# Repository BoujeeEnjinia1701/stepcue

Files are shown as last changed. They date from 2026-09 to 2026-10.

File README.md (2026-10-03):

# StepCue

     

**Area:** BioMedical · **TRL:** 3 of 9 (proof of concept on paper) · **Prototype budget:** about $200 USD · **Difficulty:** 3 of 5

Pressure-sensing insole that detects the onset of a freeze and triggers a rhythmic haptic or audio cue.

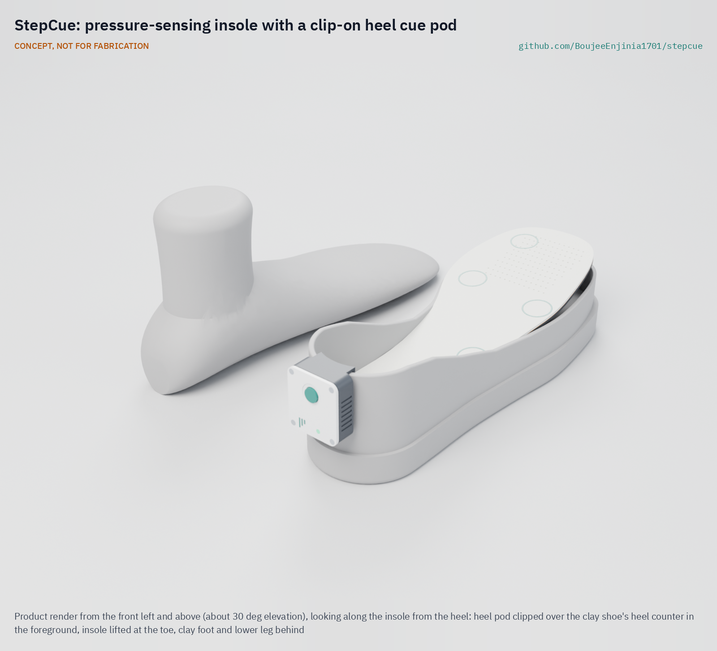
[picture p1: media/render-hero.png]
StepCue: pressure-sensing insole with a clip-on heel cue pod, product render


[Exploded render](media/render-exploded.png) · [Interactive 3D model](media/viewer.html) · [Concept blueprint (PDF)](media/concept-blueprint.pdf) · [General arrangement (PDF)](cad/drawings/STC-DWG-001.pdf) · [Sizing calculations](docs/04-calcs/01-sizing.md) · [Prototype build plan](docs/05-build-plan.md) · [Review note](docs/REVIEW.md)

## Concept rationale

Research systems that detect a freeze and cue only when it starts have mostly used accelerometers strapped to the shank, thigh or trunk, with the cue played through headphones. StepCue moves the sensing into the one place the wearer already puts on every day, the shoe: a thin insole reads how the foot is loading, a pod clipped to the heel counter holds the electronics and cell outside the shoe, and the default cue is a vibration under the arch, felt only by the wearer. Plantar pressure has predicted freezes in published work, and a foot-level design avoids straps and body-worn modules that people with reduced dexterity find hard to fit.

The design is open and garage-buildable so that the detector, the cue timing and the data format can be inspected and changed by clinics, researchers and patient groups rather than hidden in a closed product. It uses commercial force-sensing resistors, copper-tape traces on film, a common Bluetooth microcontroller module and 3D-printed parts, about $90 in parts for one instrumented insole and pod, against commercial cueing devices listed at £795 to £834. It is a research and educational prototype, not a medical device.

## Burning platform

The World Health Organization estimates that [more than 8.5 million people had Parkinson's disease in 2019 and that prevalence has doubled in the past 25 years](https://www.who.int/news-room/fact-sheets/detail/parkinson-disease). A meta-analysis of 29 studies put freezing of gait at [39.9 % of people with Parkinson's, rising to about 71 % after ten years with the disease](https://link.springer.com/article/10.1186/s41016-020-00197-y), and a Cochrane review notes that [most people with Parkinson's fall at least once during the course of the disease](https://www.cochrane.org/evidence/CD011574_interventions-preventing-falls-parkinsons-disease).

Cueing helps many people get moving again, but the devices that deliver it are costly and closed. The Path Finder shoe attachment is listed at [£834](https://techguide.parkinsons.org.uk/catalogue/path-finder) and the CUE1+ vibrotactile device at [£795 plus VAT](https://techguide.parkinsons.org.uk/catalogue/cue1plus), and the WHO notes that even the core medicine, levodopa, is [not accessible, available or affordable everywhere, particularly in low- and middle-income countries](https://www.who.int/news-room/fact-sheets/detail/parkinson-disease).

## Where it could be used

### By industry

| Industry | Use |
| --- | --- |
| Movement disorders research | Open reference platform for freeze detection and on-demand cueing studies, with a documented data format |
| Physiotherapy and rehabilitation | Adjustable cue tempo and a cue log to support home gait programs |
| Assistive technology and footwear | Reference design for sensing insoles that fit ordinary shoes |
| Biomedical engineering education | Teaching project in sensing, signal processing and embedded firmware with a clear safety envelope |
| Patient organizations and makerspaces | Low-cost builds for evaluation and co-design with people who freeze |

### By country or region

| Country or region | Why it matters there |
| --- | --- |
| China | About [5.1 million people with Parkinson's in 2021](https://www.sciencedirect.com/science/article/pii/S2666606524000725) (Xu et al., 2024), so low-cost cueing could reach many people |
| United Kingdom | Commercial cueing devices are listed at [£795 to £834](https://techguide.parkinsons.org.uk/catalogue/path-finder); an open design gives clinics and charities a cheaper research option |
| United States | About 930,000 people aged 45 and over with Parkinson's in 2020, projected to reach about 1.24 million by 2030 ([Marras et al., *npj Parkinson's Disease*, 2018](https://www.nature.com/articles/s41531-018-0058-0)); research groups could share one open detection platform and data format |
| India | The share of people aged 60 and over is projected to double to more than 20 % by 2050, and over 40 % of older people are in the poorest wealth quintile ([UNFPA India, 2023](https://india.unfpa.org/en/news/india-ageing-elderly-make-20-population-2050-unfpa-report)), so costly imported devices are out of reach for many |
| Sub-Saharan Africa | The WHO notes limited access to Parkinson's medicine in [low- and middle-income countries](https://www.who.int/news-room/fact-sheets/detail/parkinson-disease); a locally buildable cue aid needs no specialist supply chain |
| Brazil | About 535,000 people aged 50 and over were estimated to live with Parkinson's disease in 2024, projected to reach about 1.25 million by 2060 ([Schlickmann et al., *Lancet Regional Health: Americas*, 2025](https://www.sciencedirect.com/science/article/pii/S2667193X25000560)); locally built research devices can support rehabilitation studies |

## What sparked the idea

The starting point was the [wearable assistant built by ETH Zurich and the Tel Aviv Sourasky Medical Center in the EU Daphnet project](https://pubmed.ncbi.nlm.nih.gov/19906597/) (Bächlin et al., IEEE Transactions on Information Technology in Biomedicine, 2010). It used acceleration sensors on the legs and hip to detect freezes in ten people with Parkinson's and played a rhythmic sound to help them walk again, detecting 73.1 % of freezes at 81.6 % specificity, and most participants found the automatic cue helpful. That study proved that on-demand cueing works, and its recordings became a public benchmark, but its sensors were worn on the body and its cue was delivered through headphones. StepCue asks whether the same closed loop can live in the shoe: pressure under the foot plus a small heel pod, and a vibration the wearer feels rather than hears.

## Problem

Freezing of gait in Parkinson's causes falls, and cueing devices are expensive.

## Concept

A thin insole with five force-sensing resistors and a coin vibration motor connects by a flat flex tail to a small pod clipped over the heel of the shoe. The pod samples the pressure sensors and its own motion sensor 104 times a second, checks every 0.25 s for the pattern of a freeze, and pulses the motor at the wearer's own cadence until walking resumes; audio, where preferred, plays through a paired phone or earbuds. The TRL 3 calculations (STC-CAL-001) give $89.94 in parts for one instrumented insole and heel pod, a 4.5 mm insole stack and 12.5 days per charge (7.4 conservative). Detection speed, reliability and nuisance cues are at risk and cannot be shown without labeled data.

Full design precis: [docs/02-concept.md](docs/02-concept.md)

## Key components

- Force-sensing resistors (5)
- Laminated sensor film with a flat flex tail
- nRF52840 controller module with built-in 6-axis IMU in a clip-on heel pod
- Coin vibration motor under the arch
- 400 mAh protected LiPo cell (in the pod, outside the shoe)

The working bill of materials is in [bom/bom.csv](bom/bom.csv).

## Building the prototype

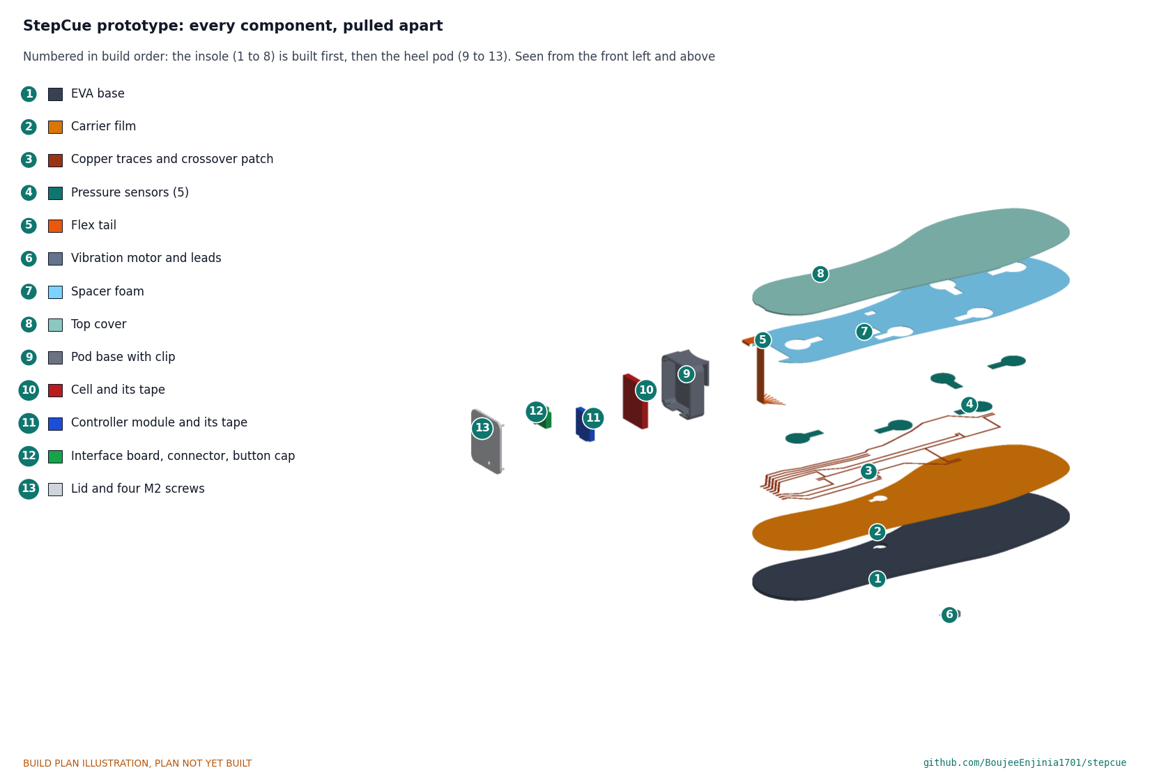
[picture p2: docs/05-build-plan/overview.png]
StepCue prototype: every component pulled apart and numbered in build order


The [prototype build plan](docs/05-build-plan.md) (STC-BLD-001) shows, in pictures, how to make each of the thirteen components and put them together in fourteen steps; nothing has been built yet. The insole is four layers cut with a knife, with a hand-laid copper tape circuit on a polyimide film joining five pressure sensors and a coin motor to a flat flex tail; the heel pod is two 3D prints holding a bought controller module, a protected cell and a hand-wired interface board. Writing the plan made the design buildable: the sensor laminate became a carrier film and a foam spacer, the motor moved into a through-hole, the tail got a connector inside the pod, the clip was curved to the heel counter and the lid gained four screws (STC-DDR-003, accepted by Amish on 2026-10-02). The insole outline is one smooth curve and the pod's corners are rounded to 5 mm with a parting-line groove. Every picture is drawn from the model, and the model checks that each part touches what it should and clears what it should not. It is a bench prototype for research and education, not a medical device.

## Safety

> This is a research and educational prototype. It is not a medical device, has not been cleared or approved by any regulator, and must not be used to diagnose, treat or monitor any person, or relied on to prevent falls. The heel pod holds a lithium cell: use a protected cell and never charge it while worn.

## Repository layout

| Folder | Contents |
| --- | --- |
| `docs/` | Problem, concept, requirements, calculations and design decisions |
| `cad/src/` | build123d Python source, the source of truth for all geometry |
| `cad/step/`, `cad/stl/` | Exported models for FreeCAD, other CAD tools and printing |
| `cad/drawings/` | 2D sketches and dimensioned drawings |
| `bom/` | Bill of materials |
| `electronics/` | KiCad schematics and PCB layouts |
| `firmware/` | Microcontroller code |
| `media/` | Renders, perspectives and photos |
| `build-log/` | Dated prototyping notes |

## Documentation

Controlled documents follow the portfolio [documentation standard](.kit/STANDARDS.md). Each carries a document ID (STC-PRC-001 for the precis), a version and a revision history. Branded PDFs are built with `python .kit/render.py` and attached to GitHub Releases when a document is tagged, for example `STC-PRC-001/v1.0`.

## Credits

Designed by Amish Chadha, with contributions from Dr. Geeti Chadha. See [CONTRIBUTORS.md](CONTRIBUTORS.md) for roles. To cite this design, use [CITATION.cff](CITATION.cff) (GitHub shows it as "Cite this repository").

AI assistance (Claude) was used to accelerate concept renders, prototype documentation and first-pass sizing calculations. Design direction and all decisions are Amish Chadha's, recorded in this repository's decision records (`docs/decisions/`).

## Licenses

- **Hardware** (CAD, drawings, BOM, electronics): [CERN-OHL-S v2](LICENSE)
- **Software** (firmware, scripts, notebooks): [MIT](LICENSE-SOFTWARE)

A project of the [Design Molecule](https://designmolecule.com) lab.

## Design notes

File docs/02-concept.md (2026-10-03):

---
doc_id: STC-PRC-001
title: StepCue design precis
project: StepCue
doc_type: Design precis
version: "0.7"
status: Draft
date: '2026-10-02'
author: Amish Chadha
license: CERN-OHL-S-2.0
revisions:
- version: "0.1"
  date: '2026-09-24'
  author: Amish Chadha
  change: Initial scaffold
- version: "0.2"
  date: '2026-09-25'
  author: Amish Chadha
  change: Populate to TRL 2 (architecture, first-order numbers, safety, media)
- version: "0.3"
  date: '2026-09-25'
  author: Amish Chadha
  change: TRL 3 (decisions D1 to D8 recorded, nRF52840 controller, piezo removed, numbers from STC-CAL-001, parametric model and STC-DWG-001)
- version: "0.4"
  date: '2026-09-25'
  author: Amish Chadha
  change: Recommendations accepted by Amish (DDR-002); 2.5 mm EVA base with motor relief, audio-route cue target, STC-DWG-001 Rev P2
- version: "0.5"
  date: '2026-10-01'
  author: Amish Chadha
  change: Design for construction (STC-DDR-003, draft); components, figures and key numbers updated from STC-CAL-001 v0.3; STC-DWG-001 Rev P3
- version: "0.6"
  date: '2026-10-02'
  author: Amish Chadha
  change: "Design for construction accepted; partner, charging, pod, traces and next model revision as decided on 2026-10-02 (STC-DEC-001)"
- version: "0.7"
  date: '2026-10-02'
  author: Amish Chadha
  change: Smooth spline insole outline and rounded pod with parting-line groove now in the model; pod mass from STC-CAL-001 v0.4; STC-DWG-001 Rev P4
---

# StepCue design precis

StepCue is a thin insole with five force-sensing resistors and a coin vibration motor, wired by a flat flex tail to a small pod that clips over the heel of the shoe. The pod reads the pressure sensors and its own motion sensor 104 times a second, decides every 0.25 s whether a freeze is starting, and if so pulses the motor at the wearer's own walking rhythm until steps resume. The calculation note STC-CAL-001 puts one unit at $89.94 in parts and 12.5 days per charge (7.4 days conservative). The insole stack is 4.50 mm against a 5.0 mm limit. Whether the detector is fast and reliable enough (R3 to R5) cannot be shown on paper and is the main risk; the calculations show those three requirements pull against one another.

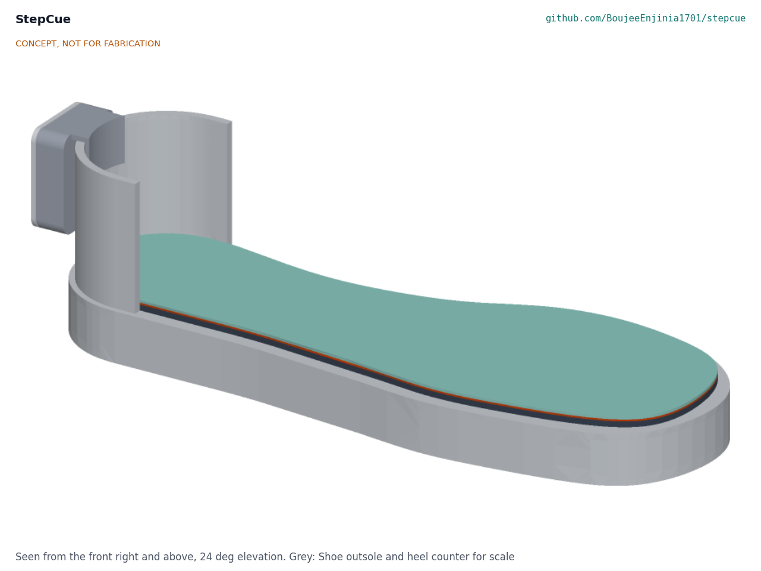
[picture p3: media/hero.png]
StepCue concept: instrumented insole in a shoe (grey), with the heel pod clipped over the heel counter


*Figure 1. Hero render from the TRL 3 parametric model. The grey shoe outsole and heel counter are shown for scale only.*

## How it works

1. **Sense.** Five force-sensing resistors (FSRs) laminated into the insole measure load under the heel, the lateral midfoot, the first and fifth metatarsal heads and the hallux. The 6-axis IMU on the controller module in the heel pod measures the motion of the shoe. All six signals are sampled at 104 Hz on the IMU's data-ready tick.
2. **Learn the wearer's rhythm.** A 30 s walk at the start of the day (or a stored value) sets the wearer's baseline cadence. Research systems such as GaitAssist used the same idea to tune cue tempo automatically ([Sweeney et al., Sensors, 2019](https://www.mdpi.com/1424-8220/19/6/1277)).
3. **Detect.** Every 0.25 s the firmware looks back over a 2 s window and computes a small set of features: whether heel strikes and toe-offs still alternate, how the center of pressure moves, the stride time compared with baseline, and the freeze index from the IMU (power in the 3 to 8 Hz freeze band divided by power in the 0.5 to 3 Hz locomotor band). The first detector is a set of thresholds; a small trained classifier replaces it once labeled data are available (decision D6). Plantar pressure alone has predicted freezes about 0.8 s before onset in the literature ([Pardoel et al., Frontiers in Neurology, 2022](https://www.frontiersin.org/articles/10.3389/fneur.2022.831063/pdf)).
4. **Cue.** When the detector fires, the coin motor under the arch pulses for 100 ms on each beat at the baseline cadence. Where the wearer prefers audio, the pod sends the beat timing over BLE to a paired phone, which plays it through its speaker or earbuds (decision D5). Cueing stops after three regular steps or 15 s, whichever comes first.
5. **Log.** Each cue is logged with a time stamp so the wearer or a clinician can later count cue events. The log leaves the pod only when the owner exports it.

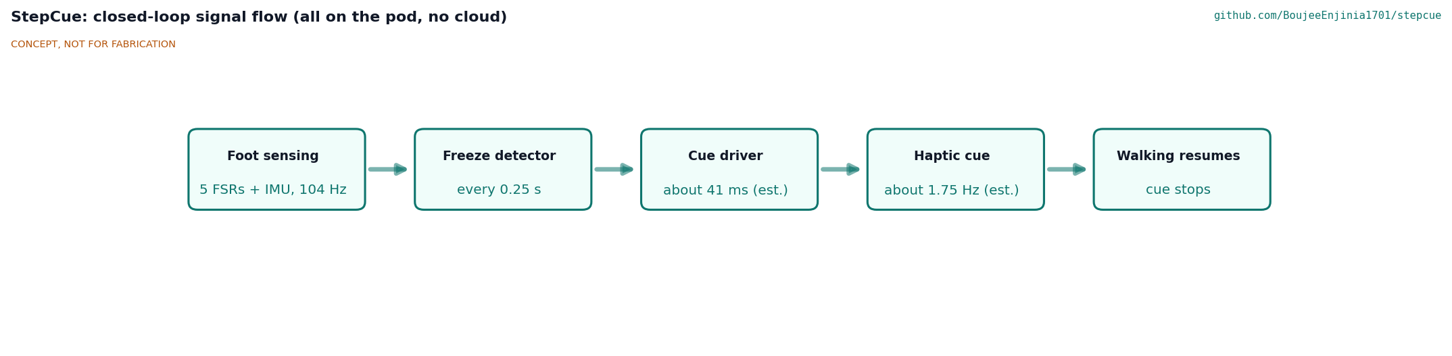
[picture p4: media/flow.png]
Closed-loop signal flow


*Figure 2. Signal flow. Values marked "est." are estimates from STC-CAL-001.*

## Main components

Table 1. Main components. Numbers match `bom/bom.csv` and the exploded view.

| # | Component | Choice | Notes |
| --- | --- | --- | --- |
| 1 | Top cover | 1.2 mm PU foam with textile face | Cut from a thin commercial insole |
| 2 | Pressure sensors | 5 Interlink FSR 402 (18.3 mm round, 0.46 mm thick) | Commercial FSRs (decision D7) |
| 3 | Sensor laminate | Two layers, 0.8 mm in all: copper tape traces on a 125 µm polyimide carrier film (0.3 mm), and a 0.5 mm closed-cell foam spacer with a window round each FSR | No custom rigid PCB (R14); the spacer foam is BOM line 14 (STC-DDR-003) |
| 4 | Flat flex tail and connector | 8-way, 1.0 mm pitch, 9 mm wide; the insole end slit into strips soldered to pads, the pod end in a ZIF connector (BOM line 13) | Runs up the inside of the heel counter under the clip finger and over its top into the pod |
| 5 | Haptic actuator | 10 x 2.7 mm coin ERM (Precision Microdrives 310-103 class) under the medial arch | Low-load site; in a hole through the base, bonded under the spacer, so nothing rigid sits under the heel or forefoot |
| 6 | Insole base | 2.5 mm EVA foam with a motor through-hole | Decision O3 (STC-DDR-002); through-hole by STC-DDR-003 |
| 7 | Heel pod base with clip | 3D-printed PETG tray, 37 mm wide, with a clip curved to the heel counter and four lid screw bosses | One-handed fitting (R12) |
| 8 | Battery | 400 mAh protected LiPo, 502535 class | Outside the shoe |
| 9 | Controller module with IMU | Seeed XIAO nRF52840 Sense class: nRF52840, LSM6DS3TR-C IMU, six analog inputs, charger, USB-C | Decision D2; USB-C faces down through a notch in the pod's bottom wall (STC-DDR-003) |
| 10 | Interface board | Perfboard with the FSR dividers, a P-MOSFET that powers them only while sampling, the motor MOSFET and diode, and a 12 mm pause button | Replaces the TRL 2 multiplexer |
| 11 | Heel pod lid | 3D-printed PETG, four M2 screws | Pause button cap and status LED windows |

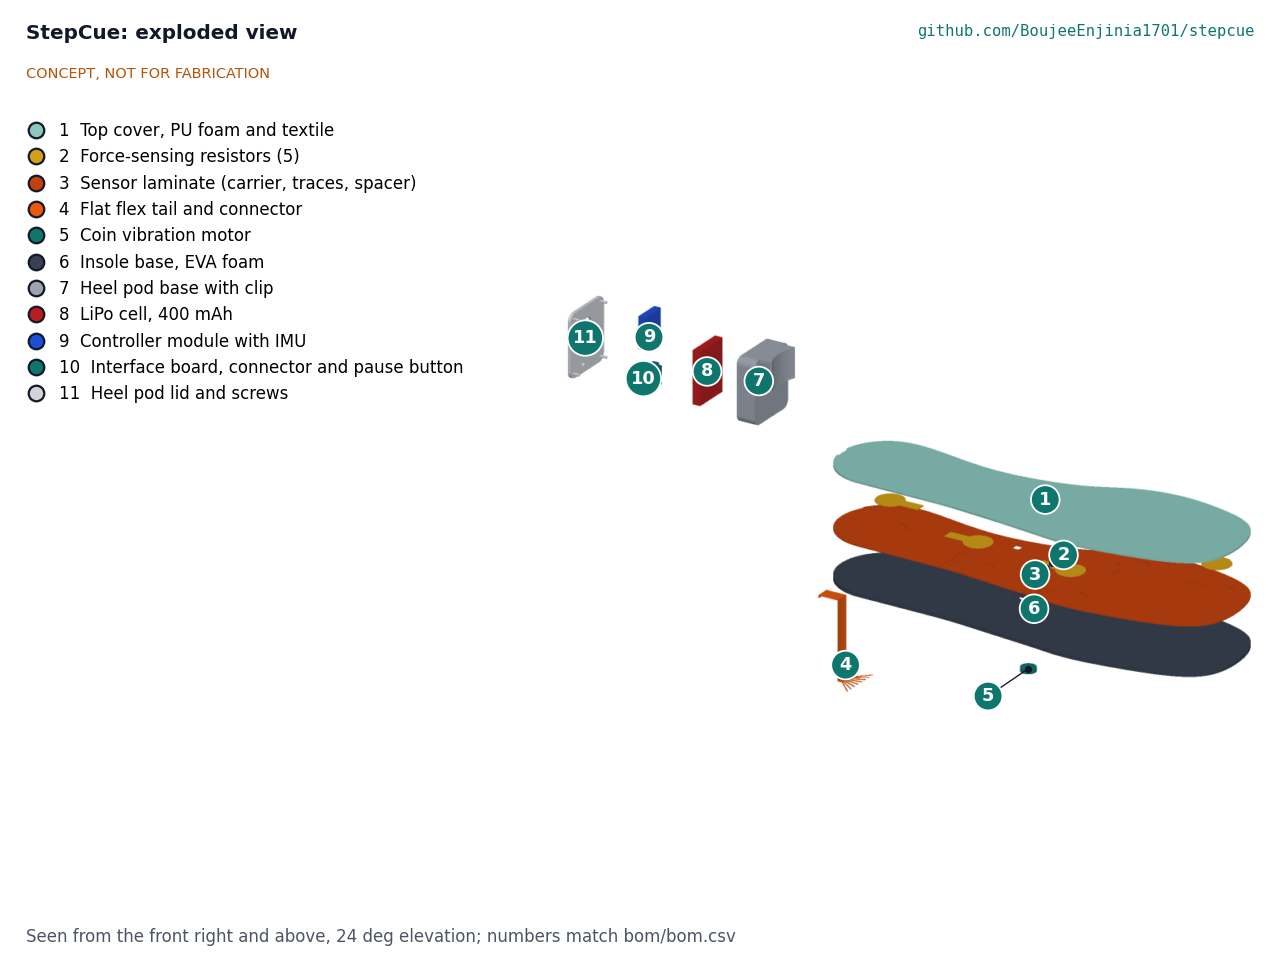
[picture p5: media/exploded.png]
Exploded view with BOM callouts


*Figure 3. Exploded view. Callout numbers match `bom/bom.csv`.*

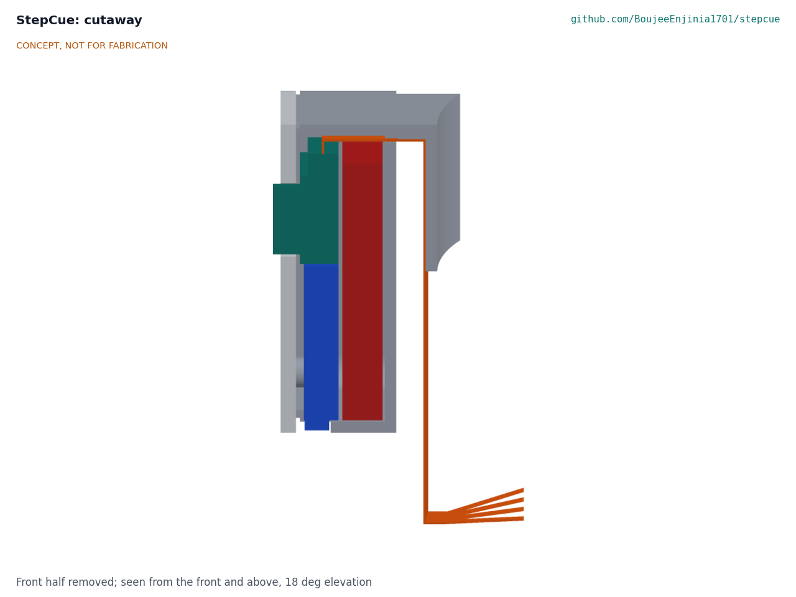
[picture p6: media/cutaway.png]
Section through the heel pod


*Figure 4. Section through the heel pod and flex tail (insole layers hidden). From the left: lid, the interface board above the controller module, the LiPo cell, and the shoe-side wall. The gap between the pod and the vertical flex tail is where the shoe's heel counter sits; the clip bridges over it and its finger presses the tail against the inside of the counter.*

The general arrangement drawing is [STC-DWG-001 Rev P4](../cad/drawings/STC-DWG-001.pdf); the parametric model is `cad/src/model.py`.

## Key numbers

All values are from STC-CAL-001 and are calculations or estimates, not measurements.

Table 2. Key numbers.

| Quantity | Value | Basis | Requirement |
| --- | --- | --- | --- |
| Sampling | 104 Hz on 6 channels | IMU data rate; Nyquist 52 Hz, 6.5 times the 8 Hz top of the freeze band | R1, R2 met |
| FSR range | Four of five sites exceed 20 N at peak load | 169 mm² active area, assumed peak pressures | R1 met; force above 20 N lost |
| Frequency resolution | 0.50 Hz | 208-sample, 2 s window | Separates the two bands |
| Detection delay | Method floor 1.50 s; 2.50 s with 5 confirming windows | Synthetic signal | R3 at risk |
| Detection accuracy | About 77 to 80 % sensitivity, 83 to 85 % specificity with pressure alone in the literature | Pardoel et al. (2022) | R4 at risk |
| Nuisance cues | 5 or more confirming windows needed at 85 % specificity | 2,400 decisions per 10 min | R5 at risk |
| Cue start after detection | 41 ms haptic; about 0.18 to 0.28 s through a phone or earbuds | Motor lag 40 ms; assumed BLE and audio latency; targets 0.1 s haptic, 0.3 s audio | R6 met |
| Cue | 203 Hz pulses, 100 ms per beat, distinct up to 130 per minute | Motor 12,200 rpm, stop time 115 ms | R7 met |
| Audio level | Earbuds above 60 dB(A); phone in a pocket about 61 dB | The removed piezo would have given 56.5 dB at 1.5 m, not the 60 dB estimated at TRL 2 | R7 met by earbuds |
| Average current while worn | 1.45 mA nominal, 2.44 mA conservative | IMU 0.90 mA plus MCU, FSR dividers, BLE | |
| Battery life | 12.5 days nominal, 7.4 days conservative | 306 mAh usable of 400 mAh | R11 met |
| Insole stack | 4.50 mm (4.3 to 4.7 mm with EVA tolerance) | 2.5 mm EVA, 0.8 mm two-layer laminate round the FSRs, 1.2 mm cover | R9 met, 0.5 mm margin |
| Heel pod | 26.8 g; 42 x 37 x 15 mm (20.3 mm deep with the clip) | Model volumes and part masses | R10 met |
| Clip | 7.5 N clamp; 6.0 N hold against 2.6 N at heel strike | PETG cantilever, 1.0 mm interference | R12 supports; not verifiable |
| Parts cost | $89.94 per unit, $110.06 under the $200 value-engineering target | `bom/bom.csv`, 14 priced lines | R14 met |

## Design choices

Amish decided the following on 2026-09-25, going with the recommendations of the TRL 2 review (STC-DDR-001).

- **One instrumented insole, not a pair (D1).** Worn on the side where the wearer reports freezing most, following the finding that one side predicts about as well as both.
- **nRF52840 module with built-in IMU (D2).** Six analog inputs remove the multiplexer, the built-in IMU removes the breakout, and sleep between samples gives about four times the battery life of the ESP32-C3 estimate.
- **Pressure plus IMU (D3).** The module's IMU lets the firmware use the well-studied freeze index alongside pressure features. The pitch is unchanged.
- **Electronics in a heel pod (D4).** Keeps the lithium cell and rigid parts out from under the foot, lets the insole be removed and dried, and allows charging off the shoe.
- **Haptic cue by default, audio through a phone or earbuds (D5).** The piezo buzzer is removed: at the heel it could not reach 60 dB at the ear.
- **Rule-based detector first (D6)**, a trained classifier only when labeled data exist.
- **Commercial FSRs (D7)** for the first build.
- **Requirement targets adopted (D8)**, with the R7 audio route and the R14 unit restated.

Amish also decided, on 2026-09-25, the two items raised at TRL 3, again going with the recommendations (STC-DDR-002):

- **Separate cue-start target for the audio route (O2).** R6 keeps 0.1 s for the haptic default and sets 0.3 s for phone or earbud audio, since latency shifts only the first beat and not the rhythm.
- **2.5 mm EVA base (O3).** The stack falls from 5.00 mm to 4.50 mm. At the time the 2.7 mm motor sat on a 0.2 mm EVA floor under a relief in the laminate; STC-DDR-003 replaces both with a through-hole, keeping the 4.50 mm stack.

On 2026-10-01, under Amish's 2026-09-30 instruction to make every design physically buildable, the model was made constructable (STC-DDR-003, accepted by Amish on 2026-10-02): a two-layer laminate, routed traces, a motor through-hole, a 9 mm tail with a connector in the pod, a curved clip, a 37 mm pod with a screwed lid and USB-C through its bottom wall. The prototype build plan is STC-BLD-001.

Decided by Amish on 2026-10-02 (STC-DEC-001): the first co-design partner is a Parkinson's patient group, recruited through a local support group affiliated with the Parkinson's Foundation (the first candidate to approach), with a physiotherapy practice brought in for the first supervised user session (O1). Insole and pod come out of the shoe together for charging in the supervised prototype sessions; an outside connector is to be decided before any take-home use. The pod is 37 mm wide with four M2 lid screws. The traces are built as modelled and checked for continuity before each wear session. The smooth insole outline and the rounded pod (5 mm corners) with a parting-line groove are now in the model, the drawing and the build plan.

## Safety

> **Safety:** StepCue is a research and educational prototype. It is not a medical device, has not been cleared or approved by any regulator, and must not be relied on to prevent falls or to guide treatment. A missed cue or a false cue could startle the wearer or leave them without help during a freeze, so any use with people who freeze must be supervised, with ethics review, and belongs to TRL 4 or later, which is on hold.

> **Safety:** The heel pod contains a lithium polymer cell. Use a protected cell, keep it outside the shoe, never charge while worn or while the pod is wet, and stop using any pod that is swollen, damaged or warm.

- Pressure points under the foot can cause skin breakdown, especially in people with reduced sensation or diabetes. Nothing rigid may sit under the heel or metatarsal heads (the FSRs are 0.46 mm), and the skin should be checked after early wear.
- The clip finger sits inside the heel counter against the wearer's heel above the insole. Its edges must be rounded and its fit checked on skin.
- The flex tail and pod must not catch on clothing or furniture, and the pod must not affect how the shoe grips or how the wearer turns.
- A sudden vibration can itself startle. Cue intensity should start low and be set with the wearer.
- The event log is health data. Keep it on the device and the owner's computer, and share only with consent. The optional phone link carries beat timing only.

## Open questions

- Labeled data: is there an openly licensed plantar-pressure freeze data set, or must the first detector be developed on IMU-only data (for example the public Daphnet set used by Bächlin et al.)? This decides whether R3 to R5 can be addressed.
- Does a heel-mounted IMU give a usable freeze index, given heel-strike impacts that shank-mounted sensors do not see?
- Can five FSRs, four of them saturating at peak load, capture the center-of-pressure features the literature uses with dense pressure insoles?
- Is a coin motor under the arch clearly felt through a sock during walking?
- How the flex tail survives thousands of heel flexes where it passes over the heel counter.

Concept media: [blueprint sheet](../media/concept-blueprint.pdf), [interactive 3D model](../media/viewer.html).

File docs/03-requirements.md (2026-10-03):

---
doc_id: STC-REQ-001
title: StepCue requirements
project: StepCue
doc_type: Requirements
version: "0.6"
status: Draft
date: '2026-10-02'
author: Amish Chadha
license: CERN-OHL-S-2.0
revisions:
- version: "0.1"
  date: '2026-09-24'
  author: Amish Chadha
  change: Initial scaffold
- version: "0.2"
  date: '2026-09-25'
  author: Amish Chadha
  change: First measurable requirements for TRL 2, with concept status
- version: "0.3"
  date: '2026-09-25'
  author: Amish Chadha
  change: Targets adopted by Amish 2026-09-25 (STC-DDR-001); R7 audio route and R14 unit restated; TRL 3 status from STC-CAL-001
- version: "0.4"
  date: '2026-09-25'
  author: Amish Chadha
  change: Recommendations accepted by Amish (DDR-002); R6 audio-route target 0.3 s; R9 met with 2.5 mm EVA base
- version: "0.5"
  date: '2026-10-01'
  author: Amish Chadha
  change: Status from STC-CAL-001 v0.3 after the design for construction (STC-DDR-003, draft); R10 and R14 figures updated, no status changed
- version: "0.6"
  date: '2026-10-02'
  author: Amish Chadha
  change: Status from STC-CAL-001 v0.4 after the model revision of 2026-10-02; R10 mass updated, no status changed
---

# StepCue requirements

Amish adopted targets R1 to R15 on 2026-09-25 (STC-DDR-001, decision D8). R7 and R14 are restated to match decisions D1 (one instrumented insole) and D5 (haptic cue by default, audio through a phone or earbuds). R6 is restated with a separate target for the audio route, decided by Amish on 2026-09-25 (STC-DDR-002, item O2). The status column gives the TRL 3 position from the calculation note STC-CAL-001 v0.4, after the design for construction changes of STC-DDR-003 (accepted by Amish on 2026-10-02) and the smooth insole outline and rounded pod decided the same day; nothing here has been measured.

Table 1. Requirements and TRL 3 status.

| ID | Requirement | Target | Verification (TRL 3 or later) | Status at TRL 3 (STC-CAL-001) |
| --- | --- | --- | --- | --- |
| R1 | Sense plantar loading at the main contact regions | 5 or more pressure sites (heel, lateral midfoot, first and fifth metatarsal heads, hallux), each sampled at 100 Hz or more | Design review; sampling calculation | Met: 5 FSRs at 104 Hz. Four sites exceed the 20 N sensor range at peak load, so force above 20 N is lost; timing and center-of-pressure features remain |
| R2 | Sense foot motion for the freeze band | 6-axis IMU at 100 Hz or more, covering the 3 to 8 Hz freeze band and the 0.5 to 3 Hz locomotor band | Datasheet; sampling calculation | Met: module IMU at 104 Hz, 0.50 Hz bins |
| R3 | Detect freezes quickly | Median delay from freeze onset to detection 2 s or less | Offline replay of labeled data | **At risk.** Method floor 1.50 s with one window, 2.50 s with the confirmation R5 needs (synthetic) |
| R4 | Detect freezes reliably | Episode sensitivity 80 % or more; window specificity 85 % or more | Offline replay of labeled data | **At risk.** Published pressure-only results are about 77 to 80 % and 83 to 85 % |
| R5 | Avoid nuisance cues | 1 false cue or fewer per 10 min of ordinary walking | Offline replay; later supervised trial | **At risk.** Needs 5 or more confirming windows at 85 % specificity |
| R6 | Start the cue promptly | Haptic cue starts 0.1 s or less after a detection; audio through a phone or earbuds starts 0.3 s or less after a detection | Firmware timing calculation | Met: haptic 41 ms; audio route about 0.18 to 0.28 s (estimate, 20 ms margin at worst) |
| R7 | Deliver a rhythmic cue the wearer can feel or hear | Haptic pulses at the wearer's baseline cadence (adjustable 60 to 130 per minute); where the wearer chooses audio, beeps of 60 dB(A) or more at the ear through a paired phone or earbuds | Calculation from datasheets; later bench measurement | Met: 203 Hz pulses stay distinct at 130 per minute; earbuds exceed 60 dB(A). Felt intensity through a sock cannot be shown on paper |
| R8 | Stop cueing when walking resumes | Cue stops within 3 regular steps, or after 15 s at most | Firmware logic review | Met by design (3 steps about 1.7 s) |
| R9 | Keep the shoe comfortable | Insole stack 5.0 mm or less; no rigid part thicker than 1 mm under the heel or metatarsal heads | Parametric model; later pressure mapping | Met: 4.50 mm with the 2.5 mm EVA base (4.7 mm at the upper EVA tolerance); FSRs 0.46 mm |
| R10 | Keep the heel pod light and small | Pod 35 g or less; body no larger than 45 x 40 x 20 mm | Parametric model; later weighing | Met: 26.8 g; 42 x 37 x 15 mm (20.3 mm deep including the clip) |
| R11 | Run a full day and more | 2 days or more between charges at 16 h per day of wear | Power budget calculation | Met: 12.5 days nominal, 7.4 days conservative |
| R12 | Usable with reduced dexterity | Pod clips on and off one-handed; USB-C charging with the pod off the shoe; one large button to pause cues | Design review; later user session | Not verifiable at TRL 3. Clip removal about 6 N by calculation; 10 mm button |
| R13 | Keep data with the wearer | Detection and cueing on the device; optional event log exported over USB or BLE by the owner only; no cloud | Design review | Met by design; the phone is used only for optional audio |
| R14 | Low cost and buildable | Parts cost $200 or less per unit, a unit being one instrumented insole and one heel pod; no custom rigid PCB for the first build | Priced BOM | Met: $89.94, $110.06 under the $200 value-engineering target |
| R15 | Safe to wear | Protected lithium cell outside the shoe; no exposed conductors; skin-contact materials suitable for footwear | Design review | Met by design |

## Requirements not met or at risk

No requirement is not met at TRL 3. R6 (audio route) and R9, listed here in STC-REQ-001 v0.3, are now met after Amish's 2026-09-25 decisions O2 and O3 (STC-DDR-002).

- **R3, R4 and R5, at risk.** The confirmation that R5 needs pushes the detection delay past R3, and published pressure-only accuracy sits at the edge of R4. None can be verified without a labeled plantar-pressure data set.
- **R12, not verifiable at TRL 3.** One-handed use needs a session with users, which is TRL 4 or later and on hold.

## Assumptions

- Freeze-related leg trembling sits in a 3 to 8 Hz band, compared with 0.5 to 3 Hz for normal stepping; this is the basis of the widely used freeze index ([Sweeney et al., 2019](https://www.mdpi.com/1424-8220/19/6/1277); [freeze index reliability, JNER 2023](https://jneuroengrehab.biomedcentral.com/articles/10.1186/s12984-023-01175-y)).
- Cueing near the person's own cadence helps, while cueing well below it can make freezing worse ([Sweeney et al., 2019](https://www.mdpi.com/1424-8220/19/6/1277), summarizing Arias and Cudeiro 2010 and Lee et al. 2012).
- Shoe size about EU 42 (US men's 8.5) for the massing model; the insole is cut to size in practice.
- Wear of 16 h per day with overnight charging.
- One instrumented insole, worn on the side where the wearer reports freezing most (decision D1).

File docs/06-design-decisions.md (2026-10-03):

---
doc_id: STC-DEC-001
title: StepCue design decisions register
project: StepCue
doc_type: Design decisions register
version: "0.3"
status: Draft
date: '2026-10-02'
author: Amish Chadha
license: CERN-OHL-S-2.0
revisions:
  - version: "0.1"
    date: '2026-10-01'
    author: Amish Chadha
    change: Register opened with the build plan; open items from STC-DDR-001 to STC-DDR-003 and the review note; budget treated as a value-engineering target
  - version: "0.2"
    date: '2026-10-02'
    author: Amish Chadha
    change: "Amish approved the recommendations for open decisions 1 to 10 (STC-DDR-003 accepted); moved to decisions made"
  - version: "0.3"
    date: '2026-10-02'
    author: Amish Chadha
    change: Smooth insole outline and rounded pod carried into the model; value engineering checked (no price change)
---

# StepCue design decisions register

Every design decision still to be made, and every decision made, in one place. Each decision is argued in full in its decision record under `docs/decisions/`; this register is the index Amish works from. The build plan (`docs/05-build-plan.md`) describes the design as it stands and does not list open decisions.

StepCue is a research and educational prototype, not a medical device.

## Open decisions

None. All open decisions were decided on 2026-10-02.

## To confirm when parts are bought

| # | What to confirm | Why it matters | Source |
| --- | --- | --- | --- |
| 1 | The pressure sensor's tail reaches about 12 mm past the disc and its two tabs are 2.54 mm apart | The tab pads on the carrier are placed for this; a longer tail moves them | STC-DDR-003, P2 |
| 2 | How far the controller module's USB-C receptacle stands past its board end (1.4 mm assumed) | Sets whether a plug seats fully in the bottom-wall notch | STC-DDR-003, P8 |
| 3 | The 8-way flat flex cable has same-side contacts and its 9 mm width matches the ZIF connector | The tail must go into the connector with its contacts toward the board | STC-DDR-003, P5 and P7 |
| 4 | The cell is 502535 class (about 35 x 25 x 5 mm) and protected | The pod's inside is sized round it, and R15 needs a protected cell | STC-CAL-001, R10 and R15 |
| 5 | The heel counter of the test shoe is about 3.5 mm thick and curved at about 32 mm radius inside | The clip's 1 mm grip and its curve are set for this counter | STC-CAL-001, R12 |
| 6 | The polyimide film takes solder at about 300 °C without lifting its adhesive | The sensors, tail strips and motor leads are soldered to pads on it | STC-DDR-003, P1 |

## Value engineering

Value-engineering target: USD 200. Estimated cost of the constructable design: USD 89.94 (USD 110.06 under the target). The target is a hypothetical control figure, not a limit; the estimate is for one instrumented insole and one heel pod, and is unchanged by the smooth insole outline and rounded pod carried into the model on 2026-10-02. Main cost drivers and savings worth trying:

- The largest lines are the controller module (USD 15.99), the sensor laminate materials (USD 15.00), the five pressure sensors (USD 14.95), the cell (USD 7.00), and the interface board parts and hardware (USD 6.00 each).
- Making the design constructable added the tail connector (USD 2.50) and the spacer foam (USD 3.00) and repriced the hardware line (USD 5.00 to USD 6.00); the estimate rose from USD 83.44 to USD 89.94.
- Savings worth trying: buy laminate materials (polyimide film, copper tape) in quantities shared across several insoles, since most of the USD 15.00 is a minimum pack; a second insole for the other foot adds about USD 47 for the insole parts alone if it shares one pod design.

## Decisions made

| Date | Decision | Decided by | Record |
| --- | --- | --- | --- |
| 2026-09-25 | TRL 2 review items D1 to D8: one instrumented insole; nRF52840 module with built-in IMU; pressure plus IMU; electronics in a clip-on heel pod; haptic cue by default with audio through a phone or earbuds; rule-based detector first; commercial FSRs; requirement targets R1 to R15 adopted | Amish: "proceed with all of your recommendations across all batches. Make sure we don't proceed to TRL 4 on any of them." | STC-DDR-001 |
| 2026-09-25 | O2: separate 0.3 s cue-start target for the phone or earbud audio route (0.1 s kept for haptic) | Amish: "i accept all your recommendations, go with them across all repos." | STC-DDR-002 |
| 2026-09-25 | O3: 2.5 mm EVA insole base, 4.50 mm stack (the motor floor and laminate relief of that decision are since replaced by a through-hole, STC-DDR-003, accepted on 2026-10-02) | Amish, same instruction | STC-DDR-002 |
| 2026-09-26 | This repo chosen for the first batch of product renders | Amish | Review note, 2026-09-26 |
| 2026-09-30 | Make the design physically buildable while drawing the build plan | Amish: "If you are realising that the design cannot be built as per concept - fix the design assumptions to match and be physically feasible as you draw the illustrations." | STC-DDR-003 (changes accepted on 2026-10-02, below) |
| 2026-10-01 | Budget treated as a value-engineering target, not a limit | Amish: "the budgets are a hypothethical control target to ensure we are thinking along a value engineering lens." | This register |
| 2026-10-02 | Design for construction accepted: the changes P1 to P12 as modelled (option a) | Amish: "i approve your recommendations for all 555 open decisions." | STC-DDR-003, Table 1 |
| 2026-10-02 | Charging: insole and pod come out of the shoe together (option a) for the supervised prototype sessions; an outside connector so the pod unplugs from the tail (option b) is to be decided before any take-home use | Amish: "i approve your recommendations for all 555 open decisions." | STC-DDR-003, A1 |
| 2026-10-02 | Pod 37 mm wide with four M2 lid screws (option a); a snap lid can follow once the pod is printed | Amish: "i approve your recommendations for all 555 open decisions." | STC-DDR-003, A2 |
| 2026-10-02 | Traces across the arch and ball of the foot: build as modelled (option a), check every trace for continuity before each wear session, and inspect after the first wear trials at TRL 4 | Amish: "i approve your recommendations for all 555 open decisions." | STC-DDR-003, A3 |
| 2026-10-02 | First co-design partner: a Parkinson's patient group, recruited through a local support group affiliated with the Parkinson's Foundation (the first candidate to approach), with a physiotherapy practice brought in for the first supervised user session | Amish: "i approve your recommendations for all 555 open decisions." | STC-DDR-001 and STC-DDR-002, O1 |
| 2026-10-02 | Hero render: the 8 degree toe-up insole tilt for the hero render only; the flat fitted state stays the reference | Amish: "i approve your recommendations for all 555 open decisions." | Review note, 2026-09-26, item 1 |
| 2026-10-02 | Smooth spline insole outline adopted at the next model revision; the traces keep their 1.5 mm edge margin (in the model since 2026-10-02) | Amish: "i approve your recommendations for all 555 open decisions." | Review note, 2026-09-26, item 2 |
| 2026-10-02 | Printed sensor rings, forefoot perforations, grip ribs, lid bezel recess and cadence mark are appearance only | Amish: "i approve your recommendations for all 555 open decisions." | Review note, 2026-09-26, item 3 |
| 2026-10-02 | Rounded pod envelope with a 5 mm corner radius and a parting-line groove adopted at the next model revision (in the model since 2026-10-02) | Amish: "i approve your recommendations for all 555 open decisions." | Review note, 2026-09-26, item 4 |
| 2026-10-02 | Clay shoe shell and foot kept for the renders only | Amish: "i approve your recommendations for all 555 open decisions." | Review note, 2026-09-26, item 5 |

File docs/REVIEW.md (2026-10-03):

# Review note: StepCue

## Session 2026-09-25: /populate to a strong TRL 2 (overnight batch run)

### What was done

- `docs/01-problem.md` (STC-PRB-001 v0.2): problem with sourced prevalence, cueing evidence, prior detection research and commercial prices; users and context; constraints; out of scope; open questions. There was no co-design checklist to keep.
- `docs/03-requirements.md` (STC-REQ-001 v0.2): 15 measurable requirements (R1 to R15) with targets, planned verification and a TRL 2 status column; a list of requirements not met; assumptions.
- `docs/02-concept.md` (STC-PRC-001 v0.2): how it works, 12 numbered components, first-order numbers, design choices, safety, open questions.
- `cad/src/concept_media.py`: massing model of a five-layer insole (cover, FSRs, laminate, motor, EVA base), flat flex tail and a clip-on heel pod (base, cell, controller, IMU, buzzer, lid), with a grey shoe outsole and heel counter as the scale context (small-object rule, as in TremorTrace).
- `media/`: `hero.png`, `concept-blueprint.png`, `.pdf` and `.svg`, `exploded.png` with BOM callouts, `cutaway.png` (heel pod section), `flow.png` (closed-loop signal flow, estimates marked), `model.glb` and `viewer.html`. Temporary `_views` folders removed.
- `bom/bom.csv`: 14 lines with indicative prices; lines 1 to 12 match the exploded-view callouts, lines 13 and 14 are not modeled.
- `README.md`: hero image and links line added before "Problem"; concept paragraph, key components and safety note updated.
- `docs/pdf/`: branded PDFs of the three controlled documents.
- `project.yaml`: unchanged. The pitch and problem are still accurate.

### Key results (estimates, to be checked at TRL 3)

| Quantity | Estimate | Requirement |
| --- | --- | --- |
| Sensing | 5 FSRs plus 6-axis IMU, 100 Hz | R1, R2 met by design |
| Cue start after detection | about 20 ms | R6 met |
| Audio at the ear | about 60 dB(A) at 1.5 m | R7 audio at risk |
| Insole stack | 5.0 mm | R9 met, no margin |
| Heel pod | about 28 g, 44 x 38 x 19 mm | R10 met |
| Average current | about 6 mA; about 100 mAh per day | |
| Battery life | about 3 days on 400 mAh (range 2 to 4) | R11 met |
| Parts cost | about $106 for one instrumented insole | R14 met; a pair (about $212) would not be |

Requirements not met or not demonstrated:

- **R3 (detection delay 2 s or less), R4 (80 % sensitivity, 85 % specificity) and R5 (1 false cue or fewer per 10 min) are not demonstrated** and cannot be on paper. R4 is at risk: published pressure-only results are about 77 to 80 % sensitivity and 83 to 85 % specificity (Pardoel et al., 2022).
- **R7 audio at risk:** a heel-mounted piezo gives about 60 dB(A) at the ear by estimate.
- **R9 has no margin** (5.0 mm against 5.0 mm).
- **R14 would not be met by a pair** of insoles; `budget_usd` ($200) is not exceeded by the proposed single-insole build, so no budget change is proposed.

### Proposed, awaiting Amish

Status update: items 1 to 7 and 9 were decided by Amish on 2026-09-25, going with the recommendations (STC-DDR-001, D1 to D8). Item 8 has no recommendation and remains proposed, awaiting Amish.

1. **One instrumented insole or a pair.** Options: (a) one insole on the side the wearer reports freezing most, about $106; (b) a pair, about $212, over budget. Recommendation: (a), since one-sided pressure data predicted freezes about as well as two-sided data in the literature.
2. **Controller.** Options: (a) ESP32-C3 (XIAO ESP32C3 class) as scaffolded, plus a separate IMU and an analog multiplexer, because that module exposes too few ADC pins for five FSRs; (b) nRF52840 with built-in IMU (XIAO nRF52840 Sense class, about $16), which has six analog inputs, lower sleep current and matches TremorTrace, removing lines 10 and 13 in part. Recommendation: (b) for battery life and shared firmware; the concept and BOM are drawn with (a) so the pitch's key components are unchanged until you decide.
3. **Add a 6-axis IMU to a "pressure-sensing insole".** Options: pressure only, or pressure plus IMU. Recommendation: pressure plus IMU (about $10 and 0.6 mA) so the firmware can use the freeze index; it does not change the pitch.
4. **Electronics in a clip-on heel pod** rather than embedded in the insole. Recommendation: heel pod (cell outside the shoe, removable for charging).
5. **Default cue.** Options: haptic under the arch, piezo audio in the pod, or audio on a phone or earbuds over BLE. Recommendation: haptic default, with phone or earbud audio as the audio route rather than the piezo, to meet R7.
6. **Detector approach.** Rule-based thresholds first, trained classifier later once labeled data exist.
7. **Sensor type.** Commercial FSRs (about $37.50 for five) or DIY piezoresistive film (a few dollars, less repeatable). Recommendation: commercial FSRs for the first build.
8. **First co-design partner:** a movement disorders clinic, a physiotherapy practice or a Parkinson's patient group.
9. **Requirement targets R1 to R15** as written in STC-REQ-001 v0.2.

### Safety concerns

- Not a medical device; must not be relied on to prevent falls. A missed or false cue during a freeze is a fall risk, so any use with people who freeze needs supervision and ethics review, which is TRL 4 or later.
- Lithium cell in the heel pod: protected cell, outside the shoe, no charging while worn or wet.
- Pressure injury under the foot, especially with reduced sensation or diabetes: nothing rigid under the heel or metatarsal heads; check skin in early wear.
- Startle from sudden vibration; snag risk from the pod and flex tail.
- The cue log is health data: local by default, shared only with consent.

### Problems and notes

- Several research pages (PubMed, PMC) blocked automated fetching, so some figures come from the open-access versions on journal, DOAJ and Parkinson's UK pages. Prevalence figures are from the abstract of the 2020 Chinese Neurosurgical Journal meta-analysis; the author list was not checked.
- In the exploded view the smallest parts (motor 5, IMU 10, buzzer 11) sit mostly behind their callout markers; the legend and BOM identify them. A kit option to offset callouts would fix this.
- The cutaway hides the insole layers (they are about 5 mm thick over 272 mm and unreadable at that scale) so the heel pod section is legible.
- The legacy `cad/src/model.py` placeholder is untouched (TRL 3 work).

### Recommended next step

Review this note and the media, then decide items 1 to 3. If you approve, run `/advance-trl3` to check the power budget, sampling, cue timing, audio level and insole stack by calculation, identify a labeled data set for the detector, and produce the parametric model and drawing sheet.

## Session 2026-09-25: TRL 3

Authority: on 2026-09-25 Amish wrote "proceed with all of your recommendations across all batches. Make sure we don't proceed to TRL 4 on any of them." This session advanced StepCue from TRL 2 to TRL 3 and stopped there.

### What was done

- `docs/decisions/0001-trl2-review-decisions.md` (STC-DDR-001 v0.1): records decisions D1 to D8 and the items still open.
- `docs/01-problem.md`, `docs/02-concept.md`, `docs/03-requirements.md` moved to v0.3: decisions recorded; nRF52840 module with built-in IMU replaces the ESP32-C3, IMU breakout and multiplexer; piezo removed in favor of phone or earbud audio; R7 audio route and R14 unit restated; TRL 3 status column; numbers replaced by STC-CAL-001 values.
- `docs/04-calcs/01-sizing.md` (STC-CAL-001 v0.1) and `docs/04-calcs/sizing.py`: FSR range and divider, sampling and window, synthetic freeze-index timing, false-cue arithmetic, cue timing, audio level, insole stack, pod mass, clip retention, power budget and cost, with a results table for R1 to R15. The script prints every number the note quotes.
- `cad/src/model.py`: parametric build123d model (insole stack, FSR sites, motor pocket, flex tail route, heel pod with clip, USB-C and tail openings, button and LED windows). Exports `cad/step/stepcue-assembly.step`, `stepcue-heel-pod.step` and part files, and `cad/stl/` for the base, lid and insole layers.
- `cad/src/sheets.py` builds `cad/drawings/STC-DWG-001` (general arrangement, Rev P1, svg, pdf and png), marked "CONCEPT, NOT FOR FABRICATION" and "PRELIMINARY, NOT FOR FABRICATION". STC-DWG-001 was free because the concept blueprint uses STC-DWG-010.
- `bom/bom.csv`: 12 lines, all priced, total $83.44 against the $200 budget; `bom/bom-notes.md` updated.
- `cad/src/concept_media.py` now builds the media from `model.py`; all media refreshed and checked (hero, blueprint, exploded with callouts 1 to 11 matching the BOM, cutaway, flow, 3D viewer). Temporary `_views` folders removed.
- `project.yaml`: trl 3, trl_target 3, evidence list extended. `README.md`: TRL badge, concept paragraph and key components updated. Pitch, problem and budget unchanged.

### Requirement status (STC-CAL-001, Table 1)

9 met, 1 not met, 4 at risk, 1 not verifiable at TRL 3.

- **Not met: R6 for the audio route.** A phone or earbud cue starts about 0.18 to 0.28 s after detection (estimate) against 0.1 s. The haptic default meets it at 41 ms.
- **At risk: R3, R4, R5.** The confirmation that R5 needs (5 consecutive windows at 85 % specificity) pushes the synthetic method floor from 1.50 s to 2.50 s, past the 2 s of R3; published pressure-only accuracy (77 to 80 %, 83 to 85 %) sits at the edge of R4. None can be verified without labeled data.
- **At risk: R9.** The insole stack is exactly 5.00 mm.
- **Not verifiable at TRL 3: R12.** One-handed use; the clip calculation supports it (7.5 N clamp, 6 N removal).
- **Met:** R1 (five FSRs at 104 Hz, though four of five sites saturate above 20 N), R2, R7, R8, R10 (25.2 g, 42 x 34 x 15 mm body), R11 (12.5 days nominal, 7.4 conservative), R13, R14 ($83.44), R15.

Corrections to TRL 2 figures: the heel piezo would give 56.5 dB at the ear, not about 60 dB (moot, since D5 removes it); battery life rises from about 3 days to 12.5 days with the nRF52840; the parts cost falls from about $106 to $83.44; the pod shrinks from 44 x 38 x 19 mm to 42 x 34 x 15 mm.

### Decisions recorded (STC-DDR-001)

Decided by Amish, 2026-09-25: go with recommendation, for D1 one instrumented insole; D2 XIAO nRF52840 Sense class controller; D3 pressure plus IMU; D4 clip-on heel pod; D5 haptic default with phone or earbud audio, no piezo; D6 rule-based detector first; D7 commercial FSRs; D8 requirement targets as written, with R7 and R14 restated. Budget kept at $200, defined as one instrumented insole and one heel pod (R14). Pitch and problem unchanged.

### Still awaiting Amish

1. **O1. First co-design partner** (movement disorders clinic, physiotherapy practice or Parkinson's patient group). No recommendation; portfolio guidance is to pick partners per area later.
2. **O2. R6 target for the audio route.** Options: keep 0.1 s and accept that audio misses it, or set 0.3 s for the audio route only. Recommendation: 0.3 s for audio, 0.1 s for haptic. Decided by Amish, 2026-09-25: go with recommendation (STC-DDR-002).
3. **O3. R9 margin.** Options: keep the 3.0 mm EVA base (zero margin) or use 2.5 mm (4.5 mm stack) with a 0.4 mm motor relief in the laminate. Recommendation: 2.5 mm. Decided by Amish, 2026-09-25: go with recommendation (STC-DDR-002).

### Safety concerns

- Not a medical device; must not be relied on to prevent falls. The calculations show that fast, reliable and quiet detection conflict, so false or late cues are likely in early firmware. Any use with people who freeze needs supervision and ethics review, which is TRL 4 or later and on hold.
- Lithium cell in the heel pod: protected cell, outside the shoe, no charging while worn or wet.
- The clip finger rests against the wearer's heel inside the counter; it needs rounded edges and a skin check.
- Pressure injury under the foot, especially with reduced sensation or diabetes; nothing rigid over 0.46 mm under the heel or metatarsal heads.
- Startle from sudden vibration; snag risk from the pod and flex tail.
- The cue log is health data: local by default, shared only with consent.

### Citations and notes

- The prevalence citation flagged at TRL 2 was checked on 2026-09-25: Ge et al., "The prevalence of freezing of gait in Parkinson's disease and in patients with different disease durations and severities," Chinese Neurosurgical Journal, 2020; 39.9 % overall, 22.4 % under 5 years, 70.8 % at 10 years or more. STC-PRB-001 now names the authors.
- New sources used at TRL 3 (FSR 402 data sheet and store price, Precision Microdrives 310-103 datasheet, Seeed XIAO nRF52840 wiki, Adafruit 3898 listing) are listed in STC-CAL-001, section 12. Plantar pressures, FSR resistance law, BLE and audio latencies, heel-strike acceleration and PETG properties are marked as assumed.
- No TRL 4 material exists in the repo; `build-log/README.md` is the original scaffold and was left untouched.

### Recommended next step

TRL 4 is on hold by Amish's instruction; no TRL 4 work was started. Next, decide O1 to O3. The most useful paper work while TRL 4 is on hold is to identify an openly licensed, labeled plantar-pressure or foot-IMU freeze data set, since R3 to R5 depend on it.

For reference only, TRL 4 would need: bench measurements of the FSR divider response and saturation, the motor's felt intensity through a sock and cover, the insole stack thickness, the pod mass and the clip retention; an offline replay of the detector on labeled data for R3 to R5; a measured power budget; and a lab test report (TST) with `environment: lab`, with ethics review before any use with people who freeze.

## Session 2026-09-25: recommendations accepted

Authority: on 2026-09-25 Amish wrote, in chat: "i accept all your recommendations, go with them across all repos." Every open item with a recommendation is now "Decided by Amish, 2026-09-25: go with recommendation". Items without a recommendation stay open. Recorded in `docs/decisions/0002-recommendations-accepted.md` (STC-DDR-002 v0.1).

### Decisions applied and what changed

- **O2, R6 audio-route target.** R6 split into 0.1 s for the haptic default and 0.3 s for phone or earbud audio. R6 moves from not met (audio 0.18 to 0.28 s against 0.1 s) to met (haptic 41 ms; audio 0.18 to 0.28 s against 0.3 s, 20 ms margin at worst on assumed latencies). Files: STC-REQ-001 v0.4, STC-CAL-001 v0.2 and `sizing.py`, STC-PRC-001 v0.4.
- **O3, 2.5 mm EVA base.** `foam_t` 3.0 mm to 2.5 mm; insole stack 5.00 mm (zero margin) to 4.50 mm (4.3 to 4.7 mm with EVA tolerance). The 2.7 mm motor sits on a 0.2 mm EVA floor and stands 0.4 mm proud into a new relief in the laminate underside, leaving 0.4 mm of laminate over it. R9 moves from at risk to met. Files: `cad/src/model.py` with STEP and STL re-exported, STC-DWG-001 Rev P1 to P2, `bom/bom.csv` lines 3 and 6 (total unchanged at $83.44), media regenerated, STC-CAL-001 v0.2, STC-REQ-001 v0.4, STC-PRC-001 v0.4.
- STC-DDR-001 v0.2 marks O2 and O3 as decided; the TRL 2 and TRL 3 sessions above are annotated.
- Budget: `budget_usd` unchanged at $200 (no budget recommendation). Pitch and problem unchanged (no rewording recommendation).
- README: "Concept rationale", "Burning platform", "Where it could be used" and "What sparked the idea" sections added before "Problem"; the inspiration point is the Daphnet wearable assistant (Bächlin et al., 2010). Media, drawings and PDFs were regenerated so the footer shows designmolecule.com.

### Requirement status (STC-CAL-001 v0.2, Table 1)

11 met, 0 not met, 3 at risk, 1 not verifiable at TRL 3 (was 9 met, 1 not met, 4 at risk, 1 not verifiable).

- **Not met:** none.
- **At risk: R3, R4, R5.** Detection delay, reliability and nuisance cues pull against one another (method floor 1.50 s, 2.50 s with the 5 confirming windows R5 needs; published pressure-only accuracy 77 to 80 % and 83 to 85 %). They need labeled data.
- **Not verifiable at TRL 3: R12** (one-handed use).
- **Met:** R1, R2, R6, R7, R8, R9, R10, R11, R13, R14, R15.

### Still awaiting Amish

1. **O1. First co-design partner** (movement disorders clinic, physiotherapy practice or Parkinson's patient group). No recommendation; proposed, awaiting Amish.

### Cross-repo actions

None. No decision in this repo needs a change elsewhere.

### Safety concerns

- Unchanged from the TRL 3 session. The thinner EVA base puts slightly less foam between the foot and the 0.46 mm FSRs; nothing rigid over 1 mm sits under the heel or metatarsal heads, and the skin check after early wear still applies.
- The 0.3 s audio target rests on assumed BLE and phone audio latencies; audio is optional and the haptic default is unaffected.

### TRL 4

TRL 4 remains on hold by Amish's instruction. No build, test, measurement, PCB, firmware or purchasing work was started. `trl: 3` and `trl_target: 3` are unchanged.

## Session 2026-09-26: sources strengthened

Three uncited rows in the README "By country or region" table were rewritten so each rests on a checked source. No budget change.

- United States: uncited claim about a university gait-research base replaced with the estimate of about 930,000 people aged 45 and over with Parkinson's in 2020 and about 1.24 million by 2030 ([Marras et al., *npj Parkinson's Disease*, 2018](https://www.nature.com/articles/s41531-018-0058-0)).
- India: uncited claim about device costs relative to incomes replaced with the UNFPA India Ageing Report 2023 figures (older share projected to double to over 20 % by 2050; over 40 % of older people in the poorest wealth quintile), citing [UNFPA India](https://india.unfpa.org/en/news/india-ageing-elderly-make-20-population-2050-unfpa-report).
- Brazil: uncited claim about the public health system and ageing replaced with the ELSI-Brazil estimate of about 535,000 people with Parkinson's disease in 2024 and about 1.25 million by 2060 ([Schlickmann et al., 2025](https://www.sciencedirect.com/science/article/pii/S2667193X25000560)).
- Kept and rechecked: WHO Parkinson's fact sheet, the freezing-of-gait meta-analysis (Springer), the Cochrane falls review and Xu et al. (2024) for China. The Parkinson's UK Technology Guide price pages and the PubMed record for Bächlin et al. (2010) could not be refetched this session (fetch restrictions and a PubMed security check); they were left unchanged.
- `docs/01-problem.md` does not repeat the rewritten rows, so it was not changed.

## Session 2026-09-26: product appearance model and photoreal renders

Amish chose this repo for the first batch of product renders on 2026-09-26. This session added an appearance model for photoreal renders; the renders themselves (`media/render-hero.png`, `media/render-exploded.png`) are produced separately from it.

### What was done

- New `cad/src/product_model.py`: `product_parts()` (24 parts: 9 shell, 13 internal, 2 context), `TITLE` and `RENDER_VIEWS` (hero from the front left and above at 30 deg, looking along the insole from the heel; exploded from the front left and above at 28 deg). It imports `PARAMS`, `derived()`, `build_parts()` and `outline()` from `model.py` and keeps every main dimension and interface: insole stack thicknesses, the five FSR sites, the motor pocket and laminate relief, the flex tail route over the counter, the pod envelope, clip bridge and finger, the USB-C, tail, pause button and LED openings, and the internal envelopes.
- Appearance detail added:
  - Insole: smooth spline outline through the model's outline points; light textile top cover with a filleted edge, printed teal rings over the five sensor sites and a field of forefoot perforations; FSRs with visible active areas; amber polyimide laminate with indicative copper traces from each sensor to the tail pad; dark EVA base.
  - Heel pod: filleted graphite base with a parting-line groove, ribbed side grips and a filleted clip; light lid with a recessed bezel, teal pause button cap, lit status LED light pipe, a small raised cadence mark and four M2 lid screws; stadium USB-C opening.
  - Internals dressed from the model envelopes: LiPo pouch with label, controller PCB with shield can and USB-C receptacle, perfboard with tact switch and MOSFETs, tail connector.
  - Context (clay): a smooth shoe shell whose heel counter matches `counter_t` and `counter_h`, and a smooth left foot and lower leg standing beside it.
- README hero image now points to `media/render-hero.png`, with an "Exploded render" link added to the links line.
- Self-check previews made with the kit renderer in `/tmp/stepcue-prod/` (not part of the repo).

### Where the appearance model differs from `model.py` (each proposed, awaiting Amish)

1. **Insole lifted at the toe in the hero pose.** The insole layers are tilted 8 deg toe-up about the top of the heel so the sensor-site rings read in the render; the flex tail's bonded pad tilts with them while the run up the counter stays put. Proposed, awaiting Amish. Recommendation: keep for the render only; the fitted, flat state in `model.py` stays the reference.
2. **Smooth insole outline.** The layers use a periodic spline through the same `outline()` points instead of the model's polygon. Proposed, awaiting Amish. Recommendation: adopt the spline in `model.py` at the next model revision; the change in area is negligible.
3. **Features not in the model or BOM wording:** printed sensor-site rings and forefoot perforations in the top cover, copper trace routing, side grip ribs, a lid bezel recess, a raised cadence mark, and four M2 lid screws (M2 screws are already in BOM line 12). Proposed, awaiting Amish. Recommendation: treat all as appearance only; if the screws are kept, the lid needs bosses at TRL 4, which is on hold.
4. **Pod split.** The lid and base share one filleted envelope with a 0.5 mm parting-line groove, so the pod reads as one product rather than a tray and a flat plate. Proposed, awaiting Amish. Recommendation: adopt the rounded envelope (5 mm corner radius) in the next model revision; it softens the edges near the wearer's heel, which the safety notes already ask for.
5. **Hero context.** The clay shoe shell replaces the model's blocky `shoe_context()` for renders only, with a clay foot beside it for scale. Proposed, awaiting Amish. Recommendation: keep for renders; leave `shoe_context()` for the concept media.

### Status

This is an appearance model only, for renders: no tolerances, PCB layout or fabrication detail. `model.py`, the BOM and the controlled documents were not changed. `trl: 3` and `trl_target: 3` are unchanged, and TRL 4 remains on hold by Amish's instruction.

## Session 2026-09-27: kit 1.5.0 and image quality

- Kit 1.5.0 synced: STANDARDS v1.5 (sections 12 to 15: product renders, storefront images and image quality, public release, authorship and signing), `.kit/cards.py`, `.kit/image_qc.py`, `.kit/release_gate.py`, issue templates, and the `/render-product` and `/release` commands. `CLAUDE.md` now matches `.kit/CLAUDE.md`.
- Every `media/render-*.png` recaptioned from its original render with the new layout: the title, concept label and repository sit in a band above the render and the view note in a band below it, each line wrapped to the image width, so no text overlaps other text or the render or runs off the image. `media/card.png` and `media/social-preview.png` regenerated with the same rules.
- `python .kit/image_qc.py` and `python .kit/release_gate.py` pass. trl stays 3.

## Session 2026-10-01: kit 1.7.0, design for construction and illustrated build plan (BLD-001)

Run under the build plan rollout brief (kit 1.7.0) and `/build-plan` steps 1 to 5, with Amish's instruction of 2026-09-30 to "fix the design assumptions to match and be physically feasible as you draw the illustrations", his 2026-09-30 rule that open decisions go in a separate register, and his 2026-10-01 rule that `budget_usd` is a value-engineering target. Commit and push were skipped by instruction (cloud copy, no git). TRL cap respected: no PCB layout, firmware, purchasing list, test plan or build log; the interface circuit is perfboard wired at block level.

### What was done

- Kit 1.7.0 installed (`.kit/`, `.claude/commands/`); `CLAUDE.md` matches `.kit/CLAUDE.md`.
- `cad/src/model.py`: made constructable (below) and given 471 build123d constructability checks (`python cad/src/model.py --check`: no overlaps, every part touches what holds it, required gaps open, traces clear of each other, the sensor discs and the edge, each pod part slides into the open tray in order, print and size limits). All 471 pass. The export now writes single parts before the assembly compounds, which had stopped the single-part STEP files being written.
- `cad/step/` and `cad/stl/`: assembly, heel pod and single parts (base, lid, foam, film, spacer, cover, laminate) regenerated.
- `cad/drawings/STC-DWG-001` Rev P3 (general arrangement), parts list now including lines 12 to 14.
- `media/`: hero, cutaway, exploded (pod parts now pulled clear behind the heel), flow, concept blueprint, `model.glb` and `viewer.html` regenerated from the constructable model (`cad/src/concept_media.py`, which can now render one image per process; key figure now about $90).
- `cad/src/build_plan_media.py` (new, uses `.kit/build_views.py`): overview, seven making sketches (`cad/drawings/STC-DWG-101` to `107`), the insole circuit layout, block wiring, eight joint close-ups and fourteen assembly step pictures in `docs/05-build-plan/`.
- `docs/05-build-plan.md` (STC-BLD-001 v0.1, new): plain-English plan by component in build order, with first checks, safety stops S1 to S7, tools, and sources. No open decisions in it.
- `docs/06-design-decisions.md` (STC-DEC-001 v0.1, new): ten open decisions, six items to confirm when parts are bought, a value engineering section and the decisions made with Amish's words.
- `docs/decisions/0003-design-for-construction.md` (STC-DDR-003 v0.1, draft): every change, with the reason.
- `docs/04-calcs/01-sizing.md` (STC-CAL-001 v0.3), `docs/03-requirements.md` (STC-REQ-001 v0.5), `docs/02-concept.md` (STC-PRC-001 v0.5), `bom/bom.csv`, `bom/bom-notes.md`: stack description, pod size and mass, cost and components updated.
- `project.yaml`: `design_state: constructable`; STC-DDR-003, STC-BLD-001 and STC-DEC-001 added to `trl_evidence`. `budget_usd` unchanged.
- `README.md`: "Prototype build plan" link and a "Building the prototype" section before "Safety"; parts figure now about $90. Credits and `CONTRIBUTORS.md` unchanged (Dr. Geeti Chadha kept as contributor).

### Design changes made for construction (STC-DDR-003, draft, open for Amish's review)

1. Sensor laminate: one solid 0.8 mm sheet became a 0.3 mm polyimide carrier with copper tape traces under a 0.5 mm closed-cell foam spacer with windows; stack unchanged at 4.50 mm.
2. Pressure sensors: tails and two solder tabs added, soldered to tab pads on the carrier; tails pointed to suit the routing.
3. Circuit: eight routed copper tape traces (0.8 mm apart, 1.5 mm inside the edge) with one insulated crossover on a polyimide patch.
4. Motor: 0.2 mm foam floor and laminate relief replaced by a through-hole in the base and carrier; motor bonded under the spacer, 1.7 mm of foam over it.
5. Flex tail: 12 mm became 9 mm (a real 8-way cable); its insole end slit into strips soldered to pads 4 mm apart.
6. Clip finger and bridge curved to the 32 mm heel counter; the flat finger and tail had cut into the counter.
7. Tail connector (ZIF, new BOM line 13) on top of the interface board; board moved above the module; tail enters through a slot under the roof.
8. Controller module turned USB-C down, the receptacle in a notch in the bottom wall.
9. Cell, module and interface board held by double-sided tapes.
10. Lid held by four M2 thread-forming screws into corner bosses; pod widened from 34 to 37 mm.
11. Pause button cap 9.4 mm, standing 1 mm out of the lid.
12. Heel notch in the spacer and cover for the tail.

### Key results

- Requirement status unchanged: 11 met, none not met, 3 at risk (R3, R4, R5), 1 not verifiable at TRL 3 (R12).
- Pod 27.2 g (was 25.2 g) against 35 g; body 42 x 37 x 15 mm against 45 x 40 x 20 mm. Clip hold 6.0 N against 2.7 N at heel strike.
- Value-engineering target: USD 200. Estimated cost of the constructable design: USD 89.94 (USD 110.06 under the target); was USD 83.44.

### Decisions proposed and awaiting Amish

All in `docs/06-design-decisions.md`: acceptance of STC-DDR-003 P1 to P12, charging with the insole and pod together (A1), 37 mm pod with screws (A2), copper traces across the flexing forefoot (A3), the first co-design partner (O1) and the five appearance-model items of 2026-09-26.

### Safety

- The build plan keeps the cell out of the pod until safety stops S2 and S3, never charges it while worn or wet, and limits any wear to the builder, standing and seated. Wear trials with people who freeze belong to later, supervised work with ethics review. StepCue is a research and educational prototype, not a medical device.
- New hazards from construction: soldering on thin film (burns, fumes) and spray contact adhesive (flammable fumes); both are covered by stop S1 and the workspace notes.

### Recommended next step

Amish reviews STC-DDR-003 and the register. TRL 4 (building and testing to the plan) stays on hold until he says otherwise.

## Session 2026-10-02: open decisions decided

Amish, 2026-10-02: "i approve your recommendations for all 555 open decisions." The recommendations written for this repo's open decisions are recorded as decided.

### Decisions recorded

10 decisions, moved from "Open decisions" to "Decisions made" in the register (STC-DEC-001 v0.2):

1. Design for construction P1 to P12 accepted as modelled (STC-DDR-003).
2. Charging: insole and pod come out together for the supervised prototype sessions; an outside connector is to be decided before any take-home use (A1).
3. Pod 37 mm wide with four M2 lid screws (A2).
4. Traces built as modelled, checked for continuity before each wear session, and inspected after the first wear trials at TRL 4 (A3).
5. First co-design partner: a Parkinson's patient group through a local support group affiliated with the Parkinson's Foundation (first candidate to approach), with a physiotherapy practice for the first supervised user session (O1).
6. The 8 degree toe-up tilt for the hero render only.
7. Smooth spline insole outline at the next model revision.
8. Sensor rings, perforations, grip ribs, bezel recess and cadence mark are appearance only.
9. 5 mm pod corner radius and parting-line groove at the next model revision.
10. Clay shoe shell and foot for the renders only.

### Documents changed

- `docs/06-design-decisions.md`: STC-DEC-001 v0.2
- `docs/decisions/0001-trl2-review-decisions.md`: STC-DDR-001 v0.3
- `docs/decisions/0002-recommendations-accepted.md`: STC-DDR-002 v0.2
- `docs/decisions/0003-design-for-construction.md`: STC-DDR-003 v0.2 (accepted; status kept Draft)
- `docs/01-problem.md`: STC-PRB-001 v0.4 (partner)
- `docs/02-concept.md`: STC-PRC-001 v0.6 (decisions paragraph)

### Follow-up actions to carry approved decisions into the design

1. Decision 2: decide the outside connector (option b) before any take-home use, and model it then (model).
2. Decision 4: add a continuity check of every trace to the checklist for each wear session when TRL 4 is opened (docs).
3. Decision 5: approach a local support group affiliated with the Parkinson's Foundation, and a physiotherapy practice for the first supervised session; nothing is agreed (docs).
4. Decision 7: change the insole outline in `cad/src/model.py` to the smooth spline, keeping the 1.5 mm trace edge margin, and regenerate the drawing and the insole outline template picture (Figure 4 of the build plan) (model, drawings, pictures).
5. Decision 9: give the pod base and lid a 5 mm corner radius and a parting-line groove in the model, and regenerate the pod making sketches and build plan pictures (model, drawings, pictures).
6. Decisions 1 and 3: regenerate the photoreal renders, card and social preview on Amish's Mac for the 37 mm pod with USB-C in the bottom wall, the curved clip and the 9 mm tail, with the render-only choices of decisions 6, 8 and 10 (pictures).

### Points found in the review

- R10 limits the pod body to 20 mm deep and the requirements table shows 20.3 mm including the clip while reporting R10 as met; it should say whether the clip counts.
- The cost is $89.94 against a $200 target, $110.06 under, so the target no longer drives any value-engineering choice; a second insole for the other foot (about $47) would still leave it well under.
- Item 2 and R12 conflict: with the connector inside the pod the pod cannot come off the shoe on its own.

## Session 2026-10-02: approved follow-ups carried out

Amish, 2026-10-02: "APPROVED CHANGES, COMPLETE THESE" for the follow-up actions of the open-decision sign-off, and "COMPLETE THESE" for the out-of-date renders, whose scenes are prepared here. Run on a cloud copy without git, so nothing was committed or pushed. TRL cap respected: no hardware, test plan or build record.

### Follow-ups

1. Decision 2 (outside connector before any take-home use): not done. The decision itself defers it until take-home use is planned; there is nothing to model yet. Stays with Amish.
2. Decision 4 (continuity check of every trace before each wear session): done in the plan. Safety stop S6 of STC-BLD-001 v0.2 now requires every one of the eight traces to read continuous, connector way to pad, before each wear, however short. The TRL 4 wear-session checklist does not exist yet; carry the same line into it when TRL 4 is opened.
3. Decision 5 (approach a local support group affiliated with the Parkinson's Foundation and a physiotherapy practice): not done. It is outreach by Amish; nothing is agreed and nothing was sent. STC-PRB-001 v0.4 already records the decision.
4. Decision 7 (smooth spline insole outline, 1.5 mm trace margin): done. `cad/src/model.py` now builds every insole layer, the shoe context and the layout from one closed spline. Its control points are the earlier outline resampled every 30 mm (so the old corners are not copied into it) plus the exact heel arc where the clip and tail fit the counter. The outline moves up to about 2.4 mm from the old polyline; every trace keeps its 1.5 mm margin and every sensor stays inside. The general arrangement (STC-DWG-001 Rev P4), the insole layout template (build plan Figure 4) and the insole making sketches STC-DWG-101 to 104 (Rev P2) are redrawn.
5. Decision 9 (5 mm pod corner radius and parting-line groove): done. Base and lid have their four long edges rounded to 5 mm (cavity 3.5 mm, so the wall stays 1.5 mm), and the base rim a 0.5 x 0.5 mm groove at the lid. The corner bosses stay inside the rounded corner and clear of the groove. Making sketches STC-DWG-105 and 107 are Rev P2; the overview, joints and steps are redrawn.
6. Decisions 1 and 3 with 6, 8 and 10 (photoreal renders, card and social preview): scenes prepared, images not made. `cad/src/product_model.py` is rebuilt on the solids of `model.py`, so it shows the 37 mm rounded pod with the parting groove, the USB-C receptacle in the bottom wall, the curved clip, the 9 mm tail, the two-layer laminate, the motor in its through-hole and the tail connector, with the render-only choices of decisions 6 (8 degree toe-up tilt), 8 (rings, perforations, grip ribs, bezel recess, cadence mark) and 10 (clay shoe and foot). Scenes for the hero and exploded views are in `/home/claude/renders/stepcue/`. `media/render-hero.png`, `render-exploded.png`, `card.png` and `social-preview.png` are to be made on Amish's Mac.

### Model and checks

- `python cad/src/model.py --check`: 485 checks, all pass (was 471). New checks: the outline is a smooth spline (tightest bend 22.6 mm radius) through its control points; base and lid corners are rounded; the cavity keeps the 1.5 mm wall round the corners; the groove leaves 1.0 mm of rim; each of the four lid bosses stays inside the rounded corner and the groove; each M2 pilot keeps 1.3 mm of plastic to the groove.
- The simplified shoe context now fits the insole with 0.02 mm clearance, so no faces coincide; it is context only.
- `cad/step/` and `cad/stl/` regenerated (assembly, heel pod and single parts).

### Results

- Requirement status unchanged: 11 met, none not met, 3 at risk (R3 to R5), 1 not verifiable at TRL 3 (R12).
- Pod mass 26.8 g (was 27.2 g) against 35 g: base 7.49 g, lid 3.62 g. Clip hold 6.0 N against 2.6 N at heel strike.
- Value-engineering target: USD 200. Estimated cost of the constructable design: USD 89.94 (USD 110.06 under the target). No price changed; `budget_usd` unchanged.

### Documents changed and new versions

- `cad/src/model.py`, `cad/src/product_model.py`, `cad/src/sheets.py`, `cad/src/build_plan_media.py`
- `docs/05-build-plan.md`: STC-BLD-001 v0.2 (outline and pod text, two rows added to the table of changes, S6 continuity check, figures)
- `docs/04-calcs/01-sizing.md`: STC-CAL-001 v0.4; `docs/03-requirements.md`: STC-REQ-001 v0.6; `docs/02-concept.md`: STC-PRC-001 v0.7; `docs/06-design-decisions.md`: STC-DEC-001 v0.3
- `bom/bom.csv` (lines 6, 7 and 11 described; masses 7.5 g and 3.6 g), `bom/bom-notes.md`
- `README.md`: parts cost corrected to $89.94 (it still said $83.44); STC-DDR-003 shown as accepted; outline and pod described
- `cad/drawings/STC-DWG-001` Rev P4; STC-DWG-101 to 105 and 107 Rev P2 (106 unchanged)
- `docs/05-build-plan/`: insole layout, overview, joints 1 to 8 and steps 1 to 14 (wiring unchanged)
- `media/`: hero, cutaway, exploded, concept blueprint, `model.glb`, `viewer.html` (flow unchanged)
- The "Stale media" note of 2026-10-01 is superseded by item 6 above; the appearance model is no longer stale. (The note itself was removed on 2026-10-02 when the renders were redone.)

### Cross-repo actions

None.

### Still open

- The review point on R10 (whether the clip counts toward the 20 mm depth) and the conflict between the charging decision and R12 remain as written on 2026-10-02, for Amish.

### Safety

No change to the safety case. StepCue remains a research and educational prototype, not a medical device; the added continuity check before each wear makes a broken trace less likely to go unnoticed.

## Session 2026-10-02: Photoreal renders redone on the constructable design

Amish, 2026-10-02: "Photoreal renders are out of date in most repos ... COMPLETE THESE". Rendered with Blender Cycles on Amish's Mac (batch F1) from the scenes exported from `cad/src/product_model.py`, captioned with `.kit/photo_caption.py`; `media/card.png` and `media/social-preview.png` regenerated with `.kit/cards.py`. Each raw render was looked at once. No commit or push; `trl` unchanged.

- Views: `media/render-hero.png`, `media/render-exploded.png` (the two views in `RENDER_VIEWS`).
- Re-render: hero and exploded, twice each. The first renders showed dark streaks across the heel pod lid face; they came from the four 1 mm countersink cones and the 0.5 to 0.3 mm lid face fillet, features too small for the edge bevel and 0.05 mm vertex merge in `.kit/photoreal.py`. In `cad/src/product_model.py` the fillet is removed (the first re-render, which still streaked), then the countersinks are filled and the M2 screws drawn as flush heads 0.15 mm proud (the second re-render, clean). Appearance only; `model.py` keeps the countersunk holes and screws. New appearance deviation, Proposed, awaiting Amish; recommendation: accept as render only.
- Kit action (not edited here): the same merge and bevel limits put faint streaks on small features in other repos; lower the merge distance or skip it for small parts.
- Appearance deviations already logged (decisions 6, 8 and 10): 8 degree toe-up tilt; sensor-site rings, perforations, grip ribs, bezel recess and cadence mark; clay shoe, foot and lower leg. Unchanged.
- `python3 .kit/image_qc.py`: 4 images, 0 problems. `python3 .kit/render.py --check`: no FAIL, and the missing render-hero warning is gone.
- The "Stale media" note of the 2026-10-01 session is removed; this work resolves it.

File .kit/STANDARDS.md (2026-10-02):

---
doc_id: OHP-STD-001
title: Documentation and drawing standard
project: Open Hardware Portfolio
doc_type: Standard
version: "1.7"
status: Released
date: 2026-09-30
author: Amish Chadha
license: CC-BY-SA-4.0
revisions:
  - version: "1.0"
    date: 2026-09-24
    author: Amish Chadha
    change: First release of the standard
  - version: "1.1"
    date: 2026-09-24
    author: Amish Chadha
    change: Adopt Technology Readiness Levels (section 9) for project maturity
  - version: "1.2"
    date: 2026-09-24
    author: Amish Chadha
    change: Portfolio phase cap (section 10), concept media standard (section 11), CLAUDE.md guardrails
  - version: "1.3"
    date: 2026-09-24
    author: Amish Chadha
    change: Scale figure, interactive 3D viewer and flow diagrams added to concept media; session slash commands
  - version: "1.4"
    date: 2026-09-26
    author: Amish Chadha
    change: Every sheet and render names the project and its GitHub repository; overall dimensions, ISO centre lines and 300 dpi PNG on sheets; titles name the device and view labels state the viewing direction; optional photoreal renders with Blender
  - version: "1.5"
    date: 2026-09-27
    author: Amish Chadha
    change: Product renders (section 12), storefront images and image quality check (section 13), public release and release gate (section 14), authorship, citation and commit signing (section 15)
  - version: "1.6"
    date: 2026-09-29
    author: Amish Chadha
    change: Licensing metadata with REUSE (section 16), Zenodo DOI and Software Heritage archiving (section 17), release gate checks REUSE and a single CITATION.cff license, archive.py
  - version: "1.7"
    date: 2026-09-30
    author: Amish Chadha
    change: Concept and constructable design states; design decisions register (DEC) kept apart from the build plan; prototype build plan (BLD, section 18) with pictures by component is required TRL 3 evidence; every repo targets TRL 3 during the populate phase; build_views.py; /to-trl3 and /build-plan commands
---

# Documentation and drawing standard

Every project in the portfolio uses this standard, so that each precis, write-up and sketch looks the same and carries its own version history. The standard ships as a kit in each repo's `.kit/` folder. The kit version is in `.kit/KIT_VERSION`.

## 1. Document types and IDs

Every controlled document has a unique ID in the form `PRJ-TYP-NNN`.

- `PRJ` is the three-letter project code listed in section 7.
- `TYP` is the document type code from the table below.
- `NNN` is a sequence number within that project and type, starting at 001.

| Code | Type | Typical file |
| --- | --- | --- |
| PRC | Design precis | `docs/02-concept.md` |
| PRB | Problem statement | `docs/01-problem.md` |
| REQ | Requirements | `docs/03-requirements.md` |
| CAL | Calculation or sizing note | `docs/04-calcs/*.md` |
| DDR | Design decision record | `docs/decisions/*.md` |
| BOM | Bill of materials | `bom/bom.csv` |
| DWG | Drawing or sketch sheet | `cad/drawings/*.svg` |
| BLD | Prototype build plan (section 18) | `docs/05-build-plan.md` |
| DEC | Design decisions register (section 18) | `docs/06-design-decisions.md` |
| TST | Test plan or test report (front matter adds `environment: lab` or `relevant`) | `docs/05-tests/*.md` |

Example: `TBK-PRC-001` is the ThermaBrick design precis.

## 2. Revision scheme

| Artifact | While in draft | When released | Change after release |
| --- | --- | --- | --- |
| Documents | 0.1, 0.2, 0.3 ... | 1.0 | 1.1 for minor edits, 2.0 for a design change |
| Drawings | Rev P1, P2 ... (preliminary) | Rev A | Rev B, C ... |

- Every change to a controlled document adds a row to its revision history before the commit.
- The `version` field in front matter always equals the newest row in `revisions`. The renderer rejects a document where they differ.
- Status is one of `Draft`, `In review`, `Released` or `Superseded`. Draft and In review documents print with a status band on every page.
- Every release is tagged in Git as `<doc_id>/v<version>`, for example `TBK-PRC-001/v1.0`. Drawings are tagged `TBK-DWG-001/revA`.
- Git history is the full audit trail. The in-document revision table is the human-readable summary.

## 3. Document front matter

Every Markdown document under version control starts with this block:

```yaml
---
doc_id: TBK-PRC-001
title: ThermaBrick design precis
project: ThermaBrick
doc_type: Precis
version: "0.1"
status: Draft
date: 2026-09-24
author: Amish Chadha
license: CERN-OHL-S-2.0
revisions:
  - version: "0.1"
    date: 2026-09-24
    author: Amish Chadha
    change: Initial draft
---
```

Quote version numbers so YAML keeps `1.0` as text instead of turning it into a number. List revisions newest last.

## 4. Writing style

- Chicago Manual of Style.
- No em dashes. Restructure the sentence instead.
- Lead each section with its conclusion, then support it.
- SI units throughout, in the form `12 kW`, `450 °C`, `3.2 m`. Imperial values may follow in parentheses.
- Number every figure and table ("Figure 2", "Table 1") and give each a caption.
- State every assumption in the calculation that depends on it.
- Put safety notes in a blockquote starting with **Safety:**.

## 5. Visual identity

| Element | Specification |
| --- | --- |
| Typeface | IBM Plex Sans for text, IBM Plex Mono for code and values (SIL Open Font License, bundled in `.kit/fonts`) |
| Ink | `#111827` |
| Secondary text | `#4B5563` |
| Rules and grid | `#D1D5DB` |
| Accent (one only) | `#0F766E` teal |
| Document page | US Letter, 20 mm margins |
| Drawing sheet | ANSI B landscape (431.8 x 279.4 mm) |
| Footer | Document ID, version, status, license and designmolecule.com on every page |

## 6. Drawing and sketch conventions

- Units are millimeters unless the title block says otherwise.
- Third-angle projection, marked with the symbol in the title block.
- Line weights: visible outlines 0.5 mm, hidden lines 0.25 mm dashed, center lines 0.18 mm chain.
- The title block contains the project, title, drawing number, revision, scale, units, projection, sheet, author, date, material or notes, and license.
- Every sheet and every render names the project and its GitHub repository (from `repo:` in `project.yaml`), at the top of the sheet and in the title block, so a printed or forwarded sheet is never anonymous.
- The drawing title names the device, not only the drawing type (for example "Handheld near-infrared resin scanner: general arrangement").
- Every view label states its scale and viewing direction (for example "Scale 1:1; side elevation looking along +Y"), and every isometric or render states where it is seen from.
- Orthographic views generated with `add_ortho` carry overall dimensions (length and depth on the top view, height on the front view) and ISO 128 centre lines on cylinders; hidden lines are dashed. Tolerances are not shown before TRL 4.
- Sheets are exported as SVG, PDF and a 300 dpi PNG.
- The revision table in the top right of the sheet lists every revision.
- Concept sketches use the same sheet and title block and carry the label "CONCEPT, NOT FOR FABRICATION".
- Geometry comes from `cad/src/*.py` (build123d). Sheets are generated by `.kit/drawing.py` and never edited by hand.

## 7. Project codes

| Code | Project | Code | Project | Code | Project |
| --- | --- | --- | --- | --- | --- |
| TBK | ThermaBrick | PCF | PicoFlow | HLT | HelioLite |
| CCB | CharCube | DRN | DustRunner | TRT | TremorTrace |
| STC | StepCue | FXH | FlexHand | CPD | ColdPod |
| SCL | SunClave | STR | SteamRoot | GGD | GrainGuard |
| SDL | SeedLine | ZBX | ZeerBox | RMS | RootMesh |
| DWD | DewDrive | SSK | StillStack | PPR | PotPress |
| WWT | WaterWatch | LMF | LumaFlow | FCL | FieldCell |
| CNP | ConePro | CVC | CulvertCrawl | EGD | EmberGuard |
| SNF | SnapFrame | CGM | CargoMule | SCM | StepClimber |
| SWC | SwapCell | PLP | PalletPilot | FTK | FlatTrike |
| WWK | WaterWalker | GRR | GrowRider | SSP | SunSpoke |
| SGN | StepGen | PBX | PowerBox | WML | WasteWise-ml |
| WSC | WasteWise Scan | RFE | ReflowEconomy | | |
| OHP | Portfolio-wide | | | | |

## 8. Build and publish

- `python .kit/render.py` checks every controlled document and renders it to `docs/pdf/<doc_id>_v<version>.pdf`.
- `python .kit/drawing.py` (called from each project's `cad/src/sheets.py`) builds drawing sheets as SVG and PDF in `cad/drawings/`.
- The GitHub Action in `.github/workflows/docs.yml` runs the checks on every push and attaches PDFs to a GitHub Release whenever a release tag is pushed.
- Public releases follow section 14: `python .kit/release_gate.py` must pass, and the release tag is `v0.<TRL>.0` (for example `v0.3.0` at TRL 3).

## 9. Technology Readiness Level (TRL)

Each project states its maturity as a Technology Readiness Level on the NASA and US DOE 1 to 9 scale. The TRL rates this specific design, not the underlying technology. A sand battery is commercial elsewhere, but a new sand battery design starts at TRL 2 until evidence shows otherwise.

| TRL | Definition | Evidence the repo must contain |
| --- | --- | --- |
| 1 | Basic principles observed | Problem statement (PRB) |
| 2 | Technology concept formulated | Draft precis (PRC) and requirements (REQ) |
| 3 | Analytical or experimental proof of concept | Calculation note (CAL), working build123d model with STEP export, drawing sheet (DWG), priced BOM with every unit cost filled in, prototype build plan (BLD) with pictures, `design_state: constructable` |
| 4 | Components validated in the lab | Test report (TST) with `environment: lab`, build log entries |
| 5 | Validated in a relevant environment | Test report (TST) with `environment: relevant` |
| 6 | System prototype demonstrated in a relevant environment | Precis at version 1.0 or later with status Released, a drawing at a lettered revision (Rev A or later), and a system-level TST with `environment: relevant` |
| 7 to 9 | Operational demonstration through proven in service | Beyond portfolio scope; claim only with a named deployment partner and evidence |

Rules:

- `project.yaml` records `trl` (current level), `trl_target` (the level the current effort aims for) and `trl_evidence` (the files that support the claim).
- `python .kit/render.py --check` fails if the evidence for the claimed TRL is missing. CI runs this check on every push.
- Documentation alone cannot go past TRL 3. TRL 4 and above require hardware and a test report.
- TRL and visibility are independent. A repo can be public at TRL 3 as a documented design ready to build.
- A change of TRL is recorded in the build log with the date and the evidence that justified it.

## 10. Portfolio phase and TRL cap

`.kit/PHASE.yaml` sets the current phase. During the **populate** phase every repo is capped at **TRL 3**: `trl` and `trl_target` may not exceed 3, and the check fails if they do. Every repo targets the cap: `trl_target` must equal 3, so a new repo is taken all the way to TRL 3 (scaffold, populate and advance, see `/to-trl3`). Work that belongs to TRL 4 or later (building or testing hardware, test articles, test plans and reports, build-log entries, purchasing lists, PCB layouts) must not be started. The prototype build plan (BLD, section 18) is TRL 3 paper work and is required. Where it already exists it is kept, flagged in the check output, and not extended. Only Amish changes `PHASE.yaml`.

Every repo carries a `CLAUDE.md` with the working rules for AI sessions: the TRL cap, decision rights (nothing is recorded as decided unless Amish decided it), one step per session, and a mandatory `docs/REVIEW.md` before stopping.

## 11. Concept media

Every repo at TRL 2 or above explains its idea visually. Media are generated from a build123d massing model with `.kit/concept.py`, never drawn by hand, so they stay in step with the design.

| File | Required | Purpose |
| --- | --- | --- |
| `media/hero.png` | TRL 2+ | Shaded isometric render with a 1.75 m person for scale; the website card image |
| `media/concept-blueprint.png` and `.pdf` | TRL 2+ | Blueprint concept sheet: orthographic and isometric views, scale, key figures, title block |
| `media/model.glb` and `media/viewer.html` | TRL 2+ | Interactive 3D viewer (glTF plus model-viewer) for the website |
| `media/cutaway.png` | When the inside matters | Section view showing internal parts |
| `media/exploded.png` | Recommended | Exploded view with numbered callouts matching the BOM |
| `media/flow.png` | When energy or material moves | System, energy or material flow diagram with losses |

Session commands in `.claude/commands/` (`/populate`, `/advance-trl3`, `/rein-in`, `/refresh-media`) carry the standard prompts, so every Claude Code session starts from the same instructions.

At TRL 2 a massing model is enough: correct overall proportions and main components. All concept media carry "CONCEPT, NOT FOR FABRICATION". The check warns when required media are missing at TRL 2 and fails at TRL 3.

## 12. Product renders

Every repo at TRL 3 shows the product as it would look, not only as a massing model.

- `cad/src/product_model.py` is the appearance model. It defines `product_parts()` (named parts with a shape and a material), `TITLE` ("Name: what it is") and `RENDER_VIEWS`. It is for renders only: every main dimension comes from `cad/src/model.py`, never typed in again.
- Where the appearance model departs from `model.py` (a chamfer, a label, a fastener drawn for realism), record the deviation in `docs/REVIEW.md` as "Proposed, awaiting Amish".
- Scale comes from context, not from a floating figure: a hand or forearm for handheld objects, and the posed mannequin (`mannequin()` in `.kit/context_parts.py`: stand, walk, push, ride, sit, reach) for anything a person uses at body scale.
- Renders are made with `.kit/export_views.py` (one scene per view) and `.kit/photoreal.py` (Blender Cycles), then captioned with `.kit/photo_caption.py`. Files are `media/render-<view>.png`; `media/render-hero.png` is required.
- Every caption names the project, the repository and the viewing direction, and carries "CONCEPT, NOT FOR FABRICATION".
- Captions never sit on the render. `.kit/photo_caption.py` adds a header band (title, concept label, repository) above the render and a footer band (view note) below it, wraps every line to the image width, and steps the font down to a floor before adding a line.
- The README opens with `media/render-hero.png`.
- Software-only and scene repositories (no single product) may use a scene render as the hero instead of a product model.

## 13. Storefront images

Two images, both made from `media/render-hero.png` by `python .kit/cards.py .`:

| File | Size | Purpose |
| --- | --- | --- |
| `media/card.png` | 800 x 800 | Square thumbnail for the organization profile page |
| `media/social-preview.png` | 1280 x 640, under 1 MB | GitHub social preview, shown when a repository link is shared |

- The social preview shows the area, name, one-line description, the first sentence of the pitch, the brand line and the repository address. Design Molecule repos read "Design Molecule · open hardware concept, TRL n"; OpenRatio repos read "OpenRatio · research and educational prototype, TRL n".
- GitHub has no API for the social preview. Upload it under the repository's Settings, Social preview, on release day.
- Regenerate both images whenever `render-hero.png` changes.

### Image quality

Every render, card and social preview must be clear and readable. `python .kit/image_qc.py` checks each one, and the release gate blocks on any failure:

| Check | Rule |
| --- | --- |
| Layout | Made by the current `photo_caption.py` or `cards.py`, which store the text layout in the PNG |
| Text inside the image | Every line at least 1.2 % of the image width from each edge; nothing runs off the side |
| No overlap | No line of text touches another line, and no caption text sits on the render |
| Text size | Render captions at least 1.05 % of the image width in pixel height (17 px at 1600 px); social preview text at least 16 px |
| Resolution | Renders at least 1200 px wide; card 800 x 800; social preview 1280 x 640 and under 1 MB |
| Sharpness | The render is not blurred or upscaled (edge sharpness at least 15 on the `image_qc.py` scale) |

Long titles and notes wrap to more lines rather than shrinking below the floor. The social preview shortens the pitch sentence with an ellipsis only if it cannot fit at the smallest size.

## 14. Public release

A repository goes public only when Amish approves it, and only after `python .kit/release_gate.py` passes. The gate checks:

1. `render.py --check` passes (document control, TRL cap, concept media).
2. Storefront: hero render, card, social preview under 1 MB, README leading with the hero, and every image passing the image quality check (section 13).
3. Issue templates in `.github/ISSUE_TEMPLATE/`: question, build report, design suggestion. The build report template restates that the design is a TRL 3 concept, not released for fabrication (OpenRatio: a research and educational prototype, not a medical device).
4. `CITATION.cff` valid, with an author ORCID.
5. License files match `project.yaml`.
6. No em dashes in the repository's own text.
7. BioMedical and OpenRatio repos use soft, non-clinical wording: "research and educational prototype, not a medical device".
8. No secrets anywhere in the history (gitleaks).
9. No links to sibling repositories that are still private.
10. REUSE files present (`REUSE.toml`, `LICENSES/`, `.github/workflows/reuse.yml`) and `reuse lint` passes (section 16).
11. `CITATION.cff` names exactly one license, because Zenodo rejects a list (section 17).

It warns, without blocking, when the README lacks a Safety heading or a "not for fabrication" statement, when `CITATION.cff` has no DOI yet, and when the README lacks the Zenodo DOI, REUSE or Software Heritage badge, so a person can confirm.

On release day, per repository:

- A signed, annotated tag `v0.<TRL>.0` on `main`.
- A GitHub release with short notes (what it is, TRL, status, licenses, how to cite) and a design pack, `<repo>-v0.<TRL>.0-design-pack.zip`, holding `cad/step`, `cad/drawings`, `docs/pdf`, `bom`, README, licenses and `CITATION.cff`.
- Description from the first sentences of `pitch` (350 characters at most), website `https://designmolecule.com` (OpenRatio: `https://openratio.ai`), topics from `project.yaml`.
- Before the first release, the repository is switched on in Zenodo (section 17), so the release is archived and gets a DOI.
- Visibility switched to public last, after the release exists.
- The social preview uploaded and the organization profile updated with the new cards.
- After the release: the concept DOI written to `CITATION.cff` and a Software Heritage save requested (section 17).

The internal working files (`CLAUDE.md`, `.kit/CLAUDE.md`, `.claude/commands/`, `docs/REVIEW.md`) stay public, and open "Proposed, awaiting Amish" items stay visible as open questions (Amish, 2026-09-27).

## 15. Authorship, citation and signing

- Amish Chadha is the author of every design, ORCID 0009-0000-8079-7141. Commits are authored as Amish Chadha <amish@designmolecule.com>.
- `CITATION.cff` lists Amish (with ORCID) first, then any credited contributors; `CONTRIBUTORS.md` and the README Credits section agree with it.
- `CITATION.cff` names one license: the hardware license (CERN-OHL-S-2.0), or the software license in a software-only repository. The full split between hardware and software licenses lives in `REUSE.toml` and the README. Once the repository is archived, `CITATION.cff` carries the concept DOI in `doi:`.
- Work done with Claude carries the trailer `Co-Authored-By: Claude <noreply@anthropic.com>` (with the model name), and the README Credits section says designs are developed with AI assistance.
- Every commit and tag pushed to GitHub is signed with Amish's SSH signing key, so GitHub shows it as Verified. Commits prepared elsewhere are re-signed on Amish's Mac before they are pushed.
- Once a repository is public, its history is never rewritten.

## 16. Licensing metadata (REUSE)

Every file states its copyright and license in a machine-readable way, following the REUSE Specification 3.3 (https://reuse.software). A repository is set up with:

```
python .kit/archive.py reuse
```

This writes three things and adds the REUSE and Software Heritage badges to the README badge line:

- `REUSE.toml`, built from the licenses in `project.yaml`. Everything is under the hardware license by default. Scripts, firmware, notebooks, web viewers, workflows and agent commands are under the software license. `cad/` and `electronics/` stay under the hardware license even where they are written as Python. The bundled IBM Plex fonts are OFL-1.1 (IBM Corp.). Copyright is "<first commit year> Amish Chadha".
- `LICENSES/`, with the full text of each license used (`reuse download`). The root `LICENSE` and `LICENSE-SOFTWARE` files stay for GitHub's license detection.
- `.github/workflows/reuse.yml`, which runs the REUSE check (fsfe/reuse-action) on every push and drives the README badge.

A new kind of file that falls outside these rules gets a new annotation in `REUSE.toml` rather than a header comment. `reuse lint` must pass before every commit that adds files, and the release gate enforces it.

## 17. Archiving and DOI (Zenodo and Software Heritage)

Every public repository is archived twice, so the design stays citable and retrievable if GitHub changes.

Zenodo (a citable DOI for each release):

1. Amish's Zenodo account is linked to GitHub. Before the first release, Amish switches the repository on in Zenodo (Account, GitHub). Only Amish changes Zenodo or GitHub settings.
2. Run `python .kit/archive.py zenodo`: it makes sure `CITATION.cff` names one license and adds the Zenodo DOI badge, which uses the GitHub repository ID and always points at the latest version. Zenodo reads its metadata (title, authors with ORCID, license, keywords) from `CITATION.cff`, and rejects the whole archive when that file lists several licenses.
3. Publish the GitHub release (section 14). Zenodo archives it within minutes and mints two DOIs: a version DOI for that release and a concept DOI that stands for all versions.
4. Check the Zenodo record: title, author and ORCID, license, keywords. If Zenodo shows "Citation metadata load failed", fix `CITATION.cff`, validate it with cffconvert and publish a new patch release (for example `v0.3.2`); a failed release is never re-used.
5. Run `python .kit/archive.py zenodo --doi <concept DOI>` and commit, so GitHub's "Cite this repository" and every future archive carry the concept DOI. Every later release gets its own version DOI automatically; the concept DOI never changes.

Software Heritage (permanent source archive):

1. After the repository is public, request a save at https://archive.softwareheritage.org/save/ (origin type git, the repository URL). Anonymous requests are limited to about ten an hour, so batches are spread out.
2. The Software Heritage badge on the README resolves once the save is accepted and ingested. Later pushes are picked up by its regular crawl.

OpenRatio repositories follow the same steps when Amish approves their release.

## 18. Prototype build plan (BLD) and the constructable design

### Two design states

A design moves through two states, recorded as `design_state` in `project.yaml`:

- **Concept**: the design shows what the product does and that it works on paper (TRL 2 and the calculations of TRL 3). Parts may be simplified shapes that have never been checked for how they are made or how they join.
- **Constructable**: every part can be made with the stated process and material, and every part fits and fastens to the parts next to it. Nothing is left as a shape that cannot be cut, cast, bent, printed, machined or bought.

A repo reaches TRL 3 only when its design is constructable and its build plan shows how. Writing the build plan is how the design is made constructable: when a part cannot be made or cannot fit as modelled, change the model so it can (Amish, 2026-09-30: "fix the design assumptions to match and be physically feasible"), keep what the concept does, and record every change in a decision record "Design for construction" (DDR) and in the plan. Changes that alter what the product does, its pitch or its safety case are proposed, not made.

### What the build plan is

`docs/05-build-plan.md` (`PRJ-BLD-001`) tells a capable maker how to build the first proof-of-concept prototype, in order, component by component, and shows it in pictures. It is written before anything is built, states "Plan, not yet built" under the title and never claims results. Building and testing to it is TRL 4 work.

### Writing rules

- **Plain English.** Say "the steel plate the jack stands on", not a model parameter or variable name. No code identifiers, function names, parameter names or file paths in the body of the plan. Give sizes as numbers with units ("a 62 mm hole, centred 100 mm up from the bottom edge"). The only place file names appear is the closing "Where the numbers come from" list.
- **Pictures first.** Every component and every assembly step has a picture. A reader should be able to build from the pictures, with the words explaining what the pictures cannot show (order, force, tolerance, checks).
- **By component, in build order.** Each component is made and checked before the step that needs it.
- **Cost is not the focus.** One line in the overview may state the parts cost from the BOM; there is no cost or time section.

### Sections, in order

1. **What you are building**: the overview picture (every component pulled apart and numbered in build order) and one short paragraph.
2. **What changed to make it buildable**: a table of each change from the concept (what the concept had, what the constructable design has, why), with a picture where the change is visible. "None" if nothing changed.
3. **Making the components**: one subsection per made component, in build order, each with:
   - its making sketch (three views with overall sizes, a 3D view, where it goes, making notes), `cad/drawings/PRJ-DWG-1NN`;
   - what it is and what it is made from (material, stock size);
   - how to make it, as numbered steps (mark out, cut, drill, bend, weld, cast, print, machine, finish), with the sizes that matter;
   - how it fits the parts next to it: a close-up picture of the joint, which faces touch, what holds them (bolt, weld, pin, clip, glue), the gap or fit needed, and which side goes where;
   - the check before moving on.
   Bought components get a short subsection: what to buy (specification, not brand), and what to do to it (drill, trim, fit).
4. **Putting it together**: numbered assembly steps, each with a step picture (parts already fitted in grey, the part being fitted in colour with an arrow showing the way it goes in), the fasteners, and any hold point.
5. **First checks**: fit, movement, first power or first load, each tied to a requirement ID with a pass criterion. The plan lists them; a TRL 4 test report records them.
6. **Safety stops**: points where work stops (before energising, pressurising, loading, lifting or operating) and what must be true to carry on.
7. **Tools, skills and workspace.**
8. **Where the numbers come from**: the model, drawings, calculation note and BOM, by file name.

### Budgets are value-engineering targets

`budget_usd` in `project.yaml` is a hypothetical control target that keeps the design thinking along a value-engineering lens; it is not a spending limit (Amish, 2026-10-01: "the budgets are a hypothethical control target to ensure we are thinking along a value engineering lens. its ok to ensure wording reflects that the hypothesis budget was x - the real cost being accrued is y"). Write it that way everywhere: "Value-engineering target: USD X. Estimated cost of the constructable design: USD Y (USD Z over or under the target)." A cost requirement is reported against the target ("over the value-engineering target by USD Z"), never as a failure that needs a budget decision, and the design decisions register does not carry "raise the budget" decisions. Instead the register has a short **Value engineering** section: target, estimated cost, the main cost drivers and the savings worth trying.

### Decisions live in their own document

The build plan describes the design as it stands; it never lists outstanding decisions, open questions or items awaiting Amish (Amish, 2026-09-30: "don't log outstanding decisions in this build plan - that is not the place for it. that should be in a separate design document logged and named as such"). Those go in the **design decisions register**, `docs/06-design-decisions.md` (`PRJ-DEC-001`), which has two tables: open decisions (what is to be decided, options, recommendation, what it affects in the build, source record) and decisions made (date, decision, Amish's words where recorded, link to the decision record). Things to confirm when parts are bought (for example a panel's frame lip) are open items in the register too. The build plan may say "see the design decisions register" once, in its introduction.

### Pictures

Pictures are generated from the model by `cad/src/build_plan_media.py` using `.kit/build_views.py` (overview, component making sketches, joint close-ups, assembly steps), so they always match the model. They are written to `docs/05-build-plan/` and `cad/drawings/`. Look at every picture before committing: labels readable, nothing overlapping, the part in question clearly visible.

`render.py --check` at TRL 3 requires a BLD document, `design_state: constructable` in `project.yaml`, and `docs/05-build-plan/overview.png`.

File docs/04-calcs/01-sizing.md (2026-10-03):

---
doc_id: STC-CAL-001
title: StepCue sizing calculations
project: StepCue
doc_type: Calculation note
version: "0.4"
status: Draft
date: '2026-10-02'
author: Amish Chadha
license: CERN-OHL-S-2.0
revisions:
- version: "0.1"
  date: '2026-09-25'
  author: Amish Chadha
  change: First-principles sizing for TRL 3 against STC-REQ-001 v0.3
- version: "0.2"
  date: '2026-09-25'
  author: Amish Chadha
  change: Recommendations accepted by Amish (DDR-002); R6 audio-route target of 0.3 s and 2.5 mm EVA base with motor relief; results table rerun against STC-REQ-001 v0.4
- version: "0.3"
  date: '2026-10-01'
  author: Amish Chadha
  change: Design for construction (STC-DDR-003, draft); two-layer laminate, motor through-hole, 37 mm pod, pod mass and cost rerun against STC-REQ-001 v0.5
- version: "0.4"
  date: '2026-10-02'
  author: Amish Chadha
  change: Rerun after the model revision decided on 2026-10-02 (smooth spline insole outline, 5 mm pod corners with a parting-line groove); pod mass 26.8 g; no status changed; against STC-REQ-001 v0.6
---
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

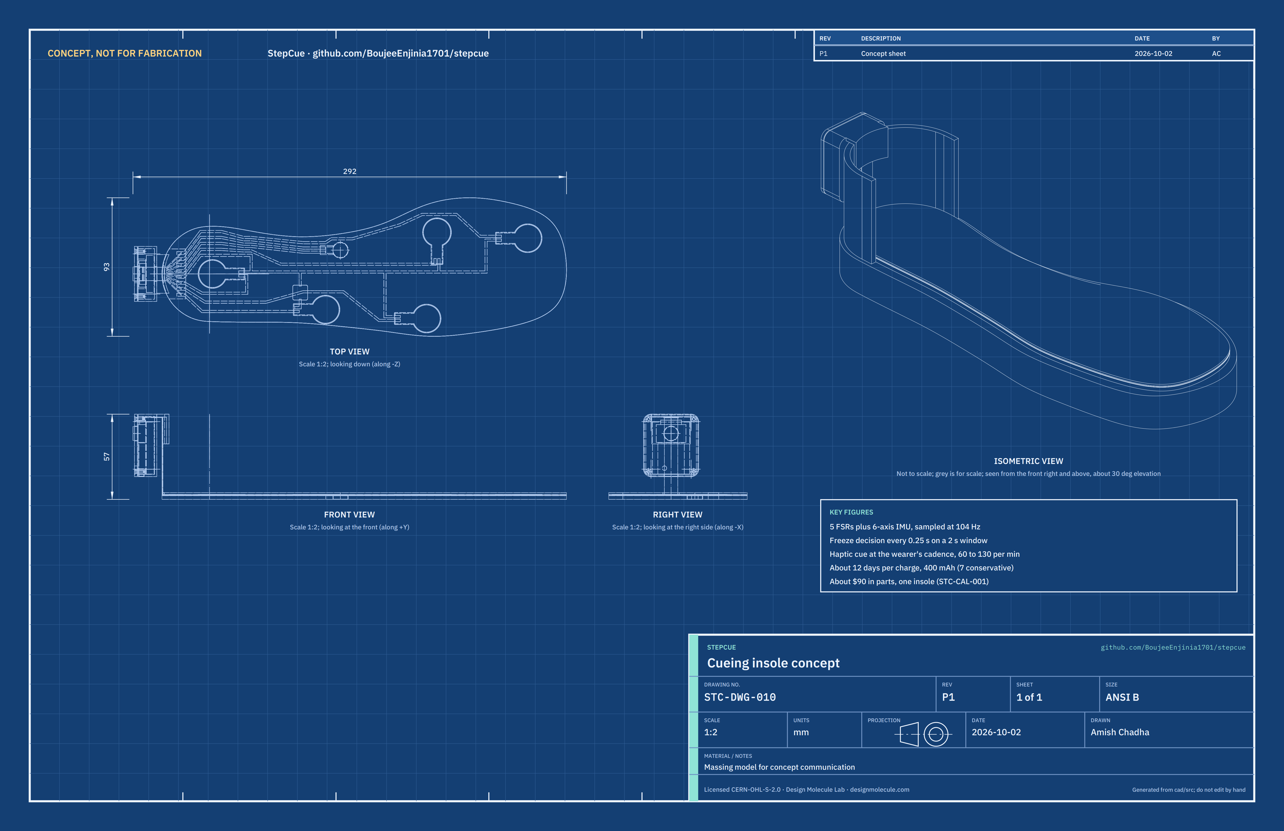
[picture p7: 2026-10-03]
media/concept-blueprint.png

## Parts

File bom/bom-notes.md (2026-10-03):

# BOM notes

- Prices are for one unit: one instrumented insole and one heel pod (decision D1 in `docs/decisions/0001-trl2-review-decisions.md`).
- Line numbers 1 to 11 match the exploded-view callouts in `media/exploded.png`. Line 12 (hardware and consumables) is partly modeled (the lid screws and tapes). Lines 13 (tail connector) and 14 (spacer foam) were added by the design for construction record STC-DDR-003; they are in the model and the build plan pictures, and the spacer is drawn as part of callout 3 in the exploded view.
- The FSR 402 price and the Adafruit 3898 cell price were checked against the supplier listings on 2026-09-25. All other prices are indicative and are confirmed at order.
- The total, USD 89.94, is checked against the value-engineering target in `project.yaml` (`budget_usd`, USD 200) by `docs/04-calcs/sizing.py` (STC-CAL-001, section 11). The target is a hypothetical control figure, not a spending limit.
- 2026-10-02 model revision (smooth insole outline; pod corners rounded to 5 mm with a parting-line groove): no line added or removed and no price changed. The pod base and lid use about 0.4 g less PETG (7.5 g and 3.6 g), well inside the failed-print allowance in their prices, so the total stays USD 89.94.
- TRL 2 lines removed by the 2026-09-25 decisions: ESP32-C3 module, separate IMU breakout, piezo buzzer and analog multiplexer.

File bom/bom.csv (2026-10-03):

item | qty | spec | supplier | unit_cost_usd | make_buy | notes
1 Top cover | 1 | 1.2 mm PU foam with textile face, cut from a thin commercial insole | Online retailer (footwear insoles) | 6.00 | buy | Indicative price
2 Force-sensing resistors | 5 | Interlink FSR 402: 18.3 mm round, 14.68 mm active, 0.46 mm thick, 0.2 to 20 N | Interlink Electronics web store or electronics distributor | 2.99 | buy | Interlink store list price checked 2026-09-25; shipping extra. Commercial FSRs decided by Amish 2026-09-25 (STC-DDR-001). The model assumes a tail reaching about 12 mm past the disc with its two tabs 2.54 mm apart; confirm on the part bought (STC-DDR-003)
3 Sensor laminate | 1 | Two layers. Carrier: 125 um polyimide film with 2 mm copper tape traces (cut to 1.5 mm) and transfer adhesive, 0.3 mm, with an 11 mm motor hole. Spacer: 0.5 mm closed-cell polyethylene foam with windows for the sensors, tail pads and motor leads (line 14). One 8 x 8 mm polyimide tape patch at the trace crossover. 0.8 mm in all | Self (materials from electronics and craft suppliers) | 15.00 | make | Material cost; indicative. Polyimide so the traces can be soldered. Two layers by STC-DDR-003 (was one 0.8 mm sheet)
4 Flat flex tail and connector | 1 | 8-way 1.0 mm pitch flat flex cable, 9 mm wide, 0.3 mm, about 100 mm, same-side contacts, tinned ends | Electronics distributor | 4.00 | buy | Indicative price. Insole end slit into eight strips and soldered to the carrier pads; pod end into line 13 (STC-DDR-003)
5 Coin vibration motor | 1 | 10 x 2.7 mm ERM, 3 V, about 58 mA, 12200 rpm (Precision Microdrives 310-103 class) | Precision Microdrives or electronics distributor | 3.00 | buy | Indicative price; specifications from the 310-103 datasheet
6 Insole base | 1 | 2.5 mm EVA foam sheet, cut to the smooth insole outline, with an 11 mm through-hole and lead notch for the motor (2.5 mm decided by Amish 2026-09-25, STC-DDR-002; through-hole by STC-DDR-003) | Online retailer (craft foam) | 4.00 | buy | Indicative price
7 Heel pod base with clip | 1 | 3D-printed PETG tray, 42 x 37 x 13 mm with 5 mm round corners and a parting-line groove, with a curved clip over the heel counter, four M2 screw bosses and a USB-C notch in the bottom wall | Self (FDM printer) | 1.50 | make | Material about 7.5 g (model volume at 1.27 g/cm3); price includes failed-print allowance. 37 mm wide (was 34) for the lid bosses, STC-DDR-003
8 LiPo cell | 1 | 400 mAh 3.7 V protected, about 35 x 25 x 5 mm (502535 class), JST-PH lead | Hobby electronics distributor (Adafruit 3898 is a 7.8 mm thick alternative) | 7.00 | buy | Indicative price; Adafruit 3898 listed at $6.95 on 2026-09-25
9 Controller module with IMU | 1 | Seeed Studio XIAO nRF52840 Sense: nRF52840, LSM6DS3TR-C IMU, 6 analog inputs, BQ25101 charger, USB-C | Seeed Studio or distributor | 15.99 | buy | Indicative list price; confirm at order. Decided by Amish 2026-09-25 (STC-DDR-001)
10 Interface board | 1 | Perfboard about 20 x 12 mm: 5 x 1 kohm divider resistors, P-MOSFET divider switch, N-MOSFET and diode for the motor, 12 mm tact switch with a 9.4 mm round cap that stands 1 mm out of the lid | Electronics distributor | 6.00 | buy | Indicative price; replaces the TRL 2 multiplexer line
11 Heel pod lid | 1 | 3D-printed PETG, 2 mm, 5 mm round corners, with pause button and LED windows and four countersunk M2 screw holes | Self (FDM printer) | 1.00 | make | Material about 3.6 g (model volume at 1.27 g/cm3); price includes failed-print allowance
12 Hardware and consumables | 1 | 4 x M2 x 6 countersunk thread-forming screws; 2-pin JST-PH lead for the cell; double-sided transfer tape 0.3 mm and foam tape 0.5 mm; polyimide tape; 30 AWG silicone wire; solder; heat-shrink | Electronics supplier | 6.00 | buy | Indicative allowance; screws and tapes are in the model, wire is not
13 Tail connector | 1 | 8-way 1.0 mm pitch ZIF flat flex connector on a small adapter board with 2.54 mm pins, about 14 x 4 x 3 mm as fitted | Electronics distributor | 2.50 | buy | Indicative price. Added by STC-DDR-003; sits on top of the interface board
14 Spacer foam | 1 | 0.5 mm closed-cell polyethylene foam sheet, about 300 x 120 mm, for the laminate spacer | Online retailer (craft or packaging foam) | 3.00 | buy | Indicative price. Added by STC-DDR-003

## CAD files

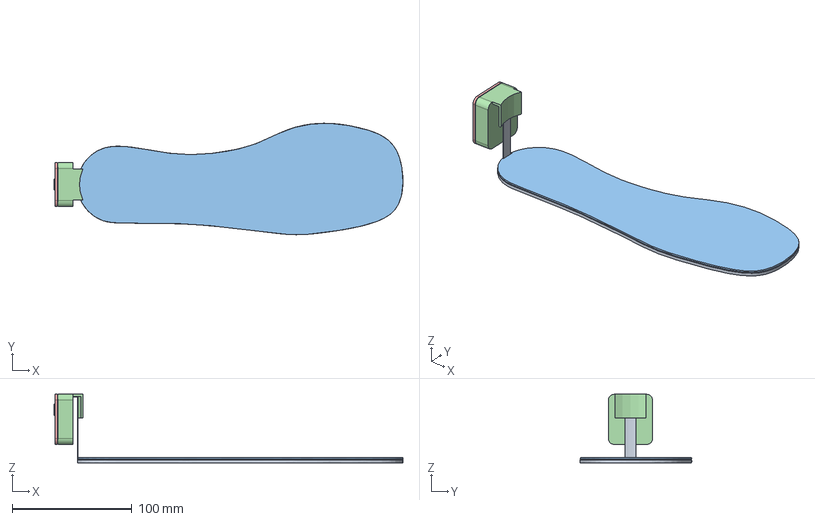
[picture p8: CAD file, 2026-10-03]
cad/step/stepcue-assembly.step
291.6 x 93.2 x 57.3 mm

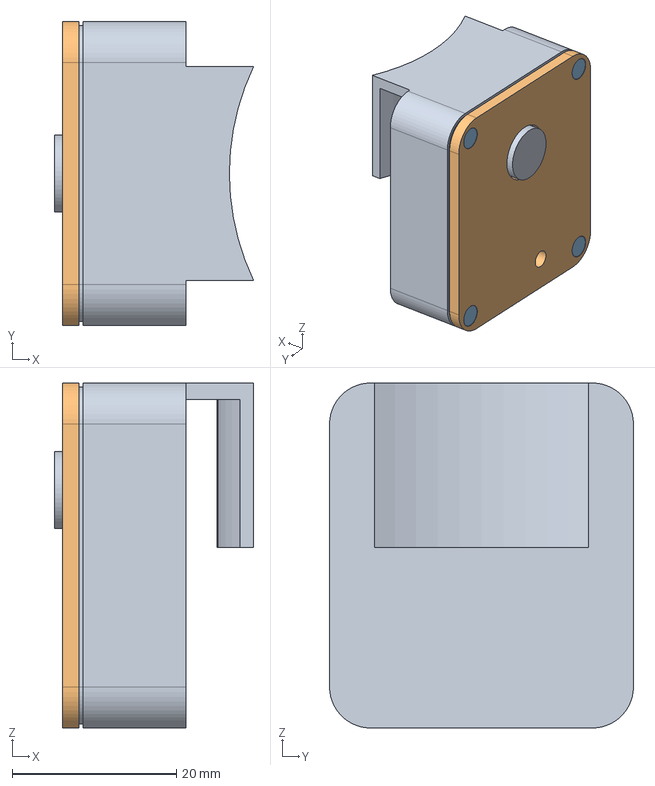
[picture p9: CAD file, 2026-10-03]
cad/step/stepcue-heel-pod.step
24.2 x 37.0 x 42.0 mm

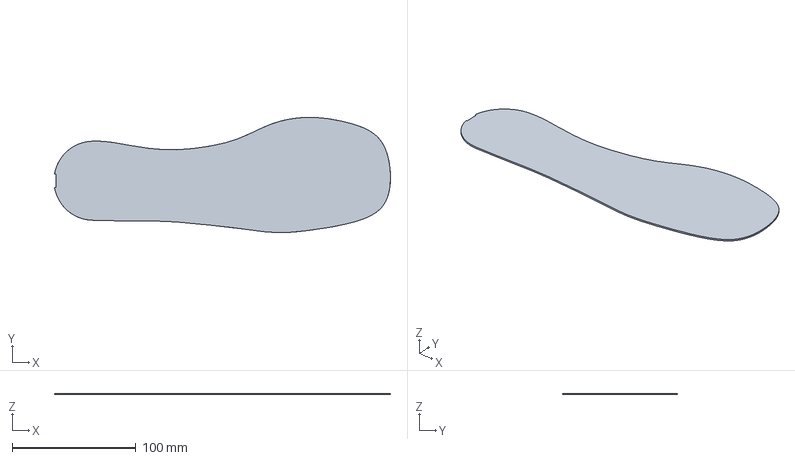
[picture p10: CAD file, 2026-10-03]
cad/step/stepcue-cover.step
271.6 x 93.2 x 1.20 mm

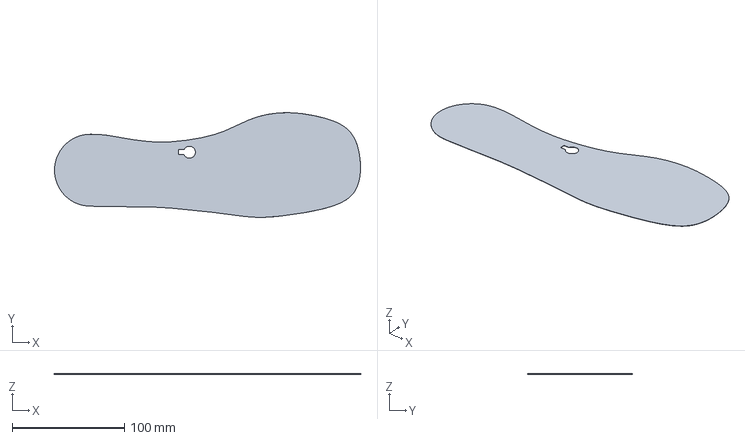
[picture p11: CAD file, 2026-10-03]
cad/step/stepcue-film.step
272.1 x 93.2 x 0.25 mm

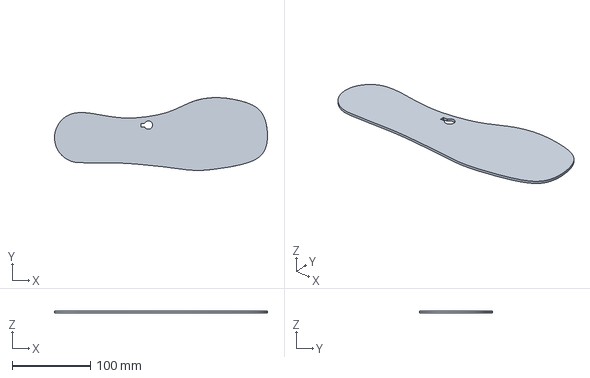
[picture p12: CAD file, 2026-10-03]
cad/step/stepcue-foam.step
272.1 x 93.2 x 2.50 mm

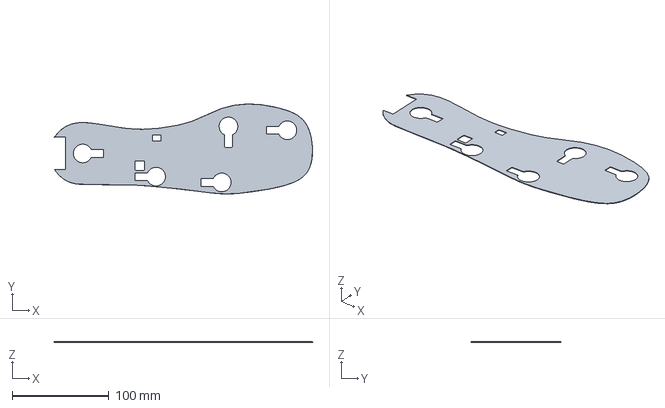
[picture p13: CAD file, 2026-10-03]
cad/step/stepcue-spacer.step
267.3 x 93.2 x 0.5 mm

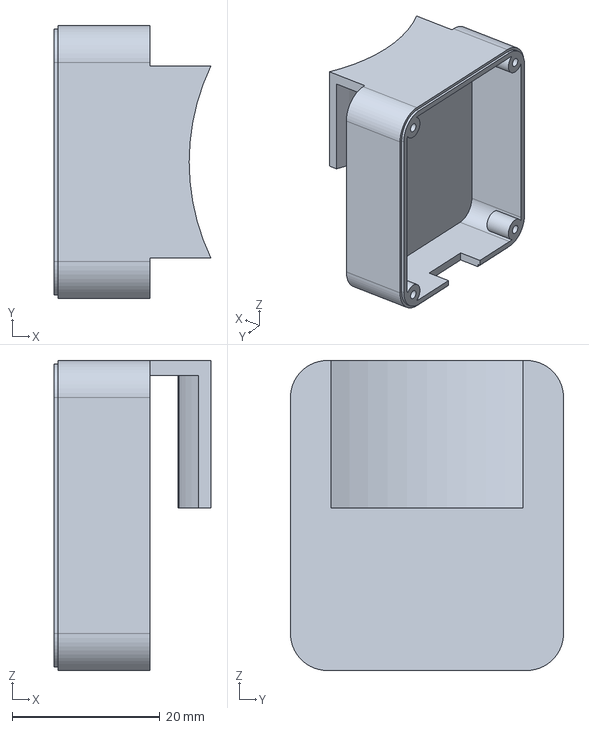
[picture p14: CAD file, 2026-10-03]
cad/step/stepcue-base.step
21.2 x 37.0 x 42.0 mm

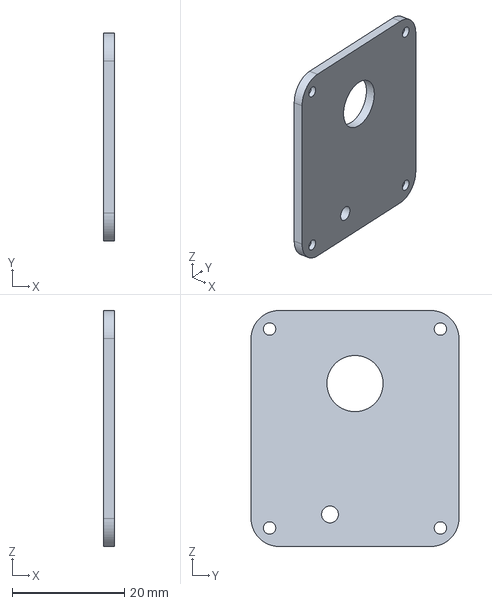
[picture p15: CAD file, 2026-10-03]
cad/step/stepcue-lid.step
2.00 x 37.0 x 42.0 mm

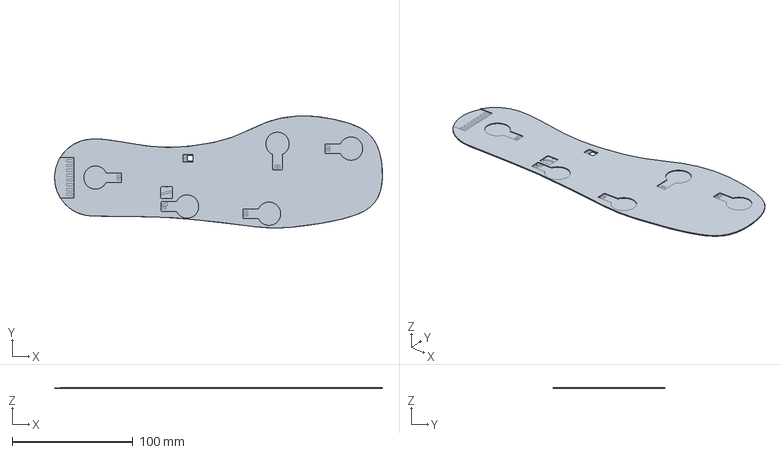
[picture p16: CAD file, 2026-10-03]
cad/step/stepcue-laminate.step
272.1 x 93.2 x 0.8 mm

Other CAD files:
cad/stl/stepcue-assembly.stl
cad/stl/stepcue-base.stl
cad/stl/stepcue-cover.stl
cad/stl/stepcue-film.stl
cad/stl/stepcue-foam.stl
cad/stl/stepcue-laminate.stl
cad/stl/stepcue-lid.stl
cad/stl/stepcue-spacer.stl

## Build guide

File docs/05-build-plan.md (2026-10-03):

---
doc_id: STC-BLD-001
title: StepCue prototype build plan
project: StepCue
doc_type: Build plan
version: "0.2"
status: Draft
date: '2026-10-02'
author: Amish Chadha
license: CERN-OHL-S-2.0
revisions:
  - version: "0.1"
    date: '2026-10-01'
    author: Amish Chadha
    change: First build plan, with pictures by component and step; design made constructable (STC-DDR-003)
  - version: "0.2"
    date: '2026-10-02'
    author: Amish Chadha
    change: Smooth spline insole outline; pod corners rounded to 5 mm with a parting-line groove; trace continuity check before every wear; pictures and sketches redrawn
---

# StepCue prototype build plan

**Plan, not yet built.** How to build the first proof-of-concept prototype, component by component. Building and testing to it is TRL 4 work. Decisions still to be made are kept in the design decisions register ([docs/06-design-decisions.md](06-design-decisions.md)), not here.

StepCue is a research and educational prototype, not a medical device. This plan builds a bench prototype only. Wearing it during walking trials, and any use with people who experience freezing of gait, belongs to later, supervised work with ethics review.

## 1. What you are building

Figure 1. Every component, pulled apart and numbered in build order

*Figure 1. Every component pulled apart and numbered in build order: the insole (1 to 8), then the heel pod (9 to 13).*

The prototype is one instrumented insole for a right shoe of about EU 42 (US men's 8.5) and a small pod that clips over the shoe's heel counter. The insole is four thin layers bonded together: an EVA foam base, a polyimide carrier film with a hand-laid copper tape circuit, a thin foam spacer, and a foam top cover cut from a bought insole. Five pressure sensors and a coin vibration motor sit in it, and a flat flex tail runs from the heel up the inside of the counter and over its top into the pod. The pod is a printed tray and lid holding a small lithium polymer cell, a bought controller module and a hand-wired interface board with a large pause button. Figure 1 shows the 13 components in the order you make or fit them. Seven are made: the four insole layers are cut with a knife (one also carries the copper circuit), the pod base and lid are 3D printed, and the interface board is built on perfboard. The rest are bought. The work is cutting foam and film, laying copper tape, fine soldering, two 3D prints and some hand wiring. The parts cost about USD 90, from the bill of materials.

> **Safety:** The pod holds a lithium polymer cell. Use a protected cell only, keep it out of the pod until section 6 says otherwise, never charge it while worn or wet, and stop using a cell that is swollen, damaged or warm. Soldering on thin film and foam is a burn and fume risk: use a fume extractor and keep the iron in its stand. Contact adhesive and its fumes are flammable: spray outdoors or in a ventilated space, away from the iron.

## 2. What changed to make it buildable

The concept showed what StepCue does; some of its parts could not be made or joined as drawn. Each change below keeps what StepCue does, and all of them are recorded in decision record STC-DDR-003, open for Amish's review.

*Table 1. Changes from the concept.*

| Component | The concept had | The buildable design has | Why |
| --- | --- | --- | --- |
| Sensor laminate | One solid 0.8 mm sheet with pockets, and no conductors | A polyimide carrier film with copper tape traces (0.3 mm) under a foam spacer with windows (0.5 mm); same 0.8 mm (Figures 3 and 4) | Each layer can be bought and cut; the sensors connect to the tail |
| Sensors | Plain discs | Each with its tail and two tabs soldered to pads (Figure 5) | That is how the sensor is joined |
| Circuit | None drawn | Eight traces, with one insulated crossover (Figures 4 and 9) | Five sensors and the motor need eight conductors on one face |
| Motor | On a 0.2 mm foam floor, in a relief cut in the laminate | In a hole through the base and the carrier, stuck under the spacer (Figure 7) | A through-hole can be punched; a 0.2 mm floor cannot be cut |
| Flex tail | 12 mm wide, laid in the laminate with no joint | 9 mm wide (8 ways), its end slit into strips soldered to pads 4 mm apart (Figure 6) | An 8-way cable is 9 mm wide; 1 mm pitch is too fine to solder by hand |
| Clip | Flat finger against a flat counter | Finger and bridge curved to the counter (Figure 12) | A real heel counter is curved; the flat finger cut into it |
| Inside the pod | Tail ended at the wall; parts held by nothing | A tail connector on top of the interface board, the board above the module, parts taped to the cell (Figure 16) | The tail reaches its connector; nothing rattles |
| Controller module | USB-C up, short of the wall | USB-C down, through a notch in the bottom wall (Figure 13) | The board must sit below the connector; the plug now seats fully |
| Lid | No fixing; tact switch short of the lid | Four M2 screws into corner bosses; a button cap 1 mm proud (Figures 17 and 18) | The lid holds everything; the button can be pressed |
| Pod width | 34 mm | 37 mm | Room for the lid bosses beside the cell |
| Insole outline | Straight runs between the heel and toe curves | One smooth curve with no corners, traces still 1.5 mm inside the edge (Figure 4) | A smooth edge cuts cleanly and sits evenly against the shoe |
| Pod corners | Square | Rounded to 5 mm, with a shallow groove where the lid meets the base (Figures 11 and 17) | Nothing to catch on clothing; the joint reads as a clean line |

## 3. Making the components

Make and check each component before the assembly step that needs it. Sizes are in millimetres. Positions on the insole are measured forward from the back of the heel and sideways from the insole's centre line, plus toward the big toe; the insole is for a right foot (mirror everything for a left foot). Workshop tolerance is 0.5 mm unless a step says otherwise; drawings do not carry tolerances before TRL 4.

### 3.1 EVA base

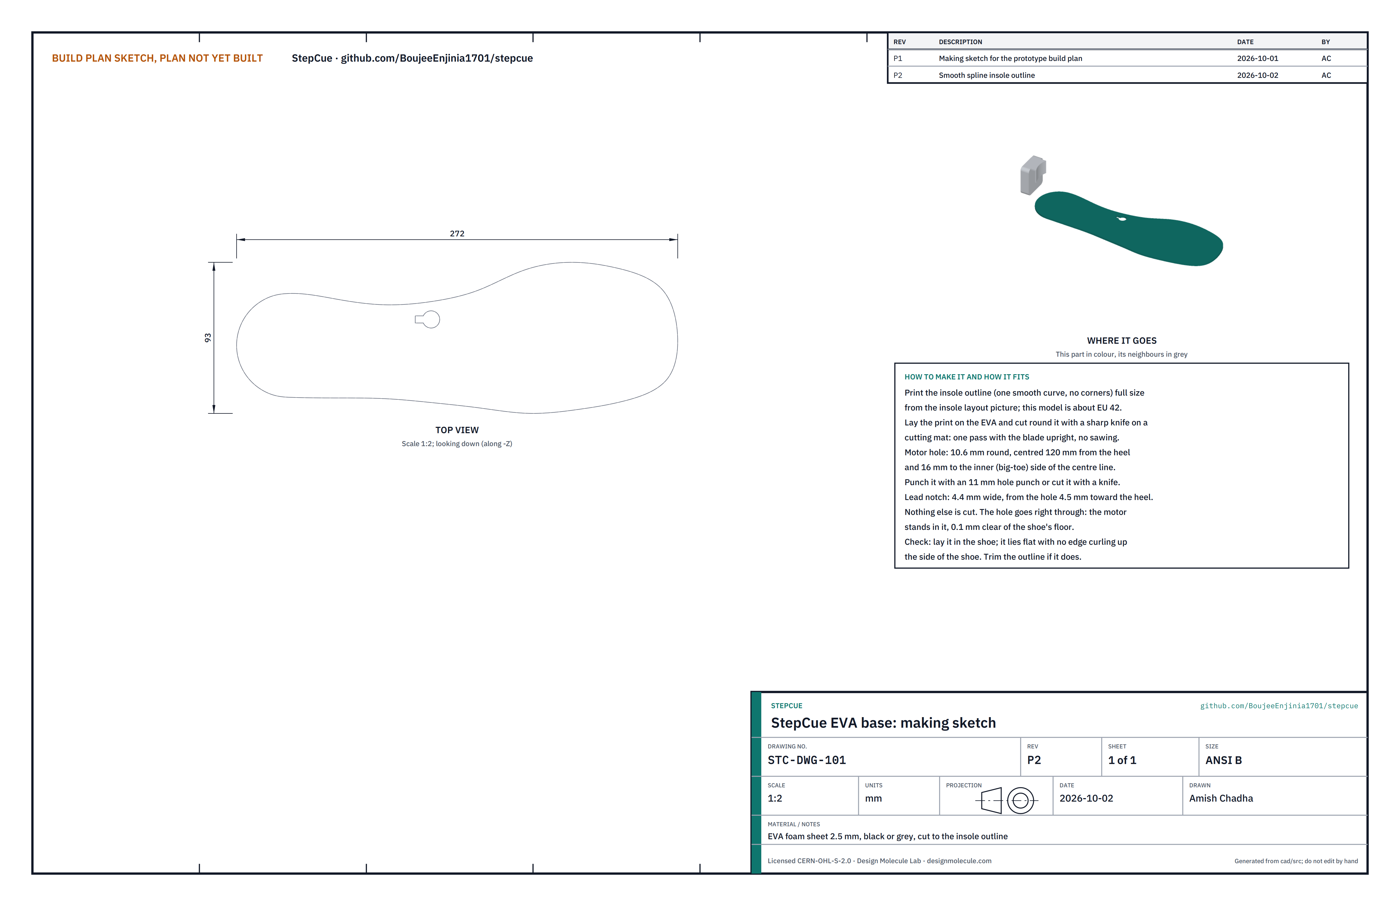
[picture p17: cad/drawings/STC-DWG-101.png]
Figure 2. Making sketch of the EVA base


*Figure 2. EVA base making sketch (STC-DWG-101).*

**What it is and what it is made from.** The bottom layer of the insole, which sits on the shoe's floor. Black or grey EVA foam sheet 2.5 mm thick.

**How to make it.**

1. Print the insole outline full size from the insole layout (Figure 4). It is one smooth curve with no corners. If you trace round the shoe's own insole instead, keep every copper trace at least 1.5 mm inside its edge. Check the print against a ruler: 272 mm long.
2. Lay the print on the foam and cut round it with a sharp knife on a cutting mat, blade upright, one steady pass.
3. Punch the motor hole, 10.6 mm (an 11 mm punch is fine), centred 120 forward and 16 toward the big toe.
4. Cut the lead notch: 4.4 mm wide, from the hole 4.5 mm toward the heel.

**How it fits the parts next to it.** The carrier film sticks to its top face with the two motor holes lined up (step 2). Its underside lies on the shoe's floor; nothing is stuck to it.

**Check before moving on.** It lies flat in the shoe with no edge climbing the shoe's side; trim the outline if it does.

### 3.2 Carrier film with the copper circuit

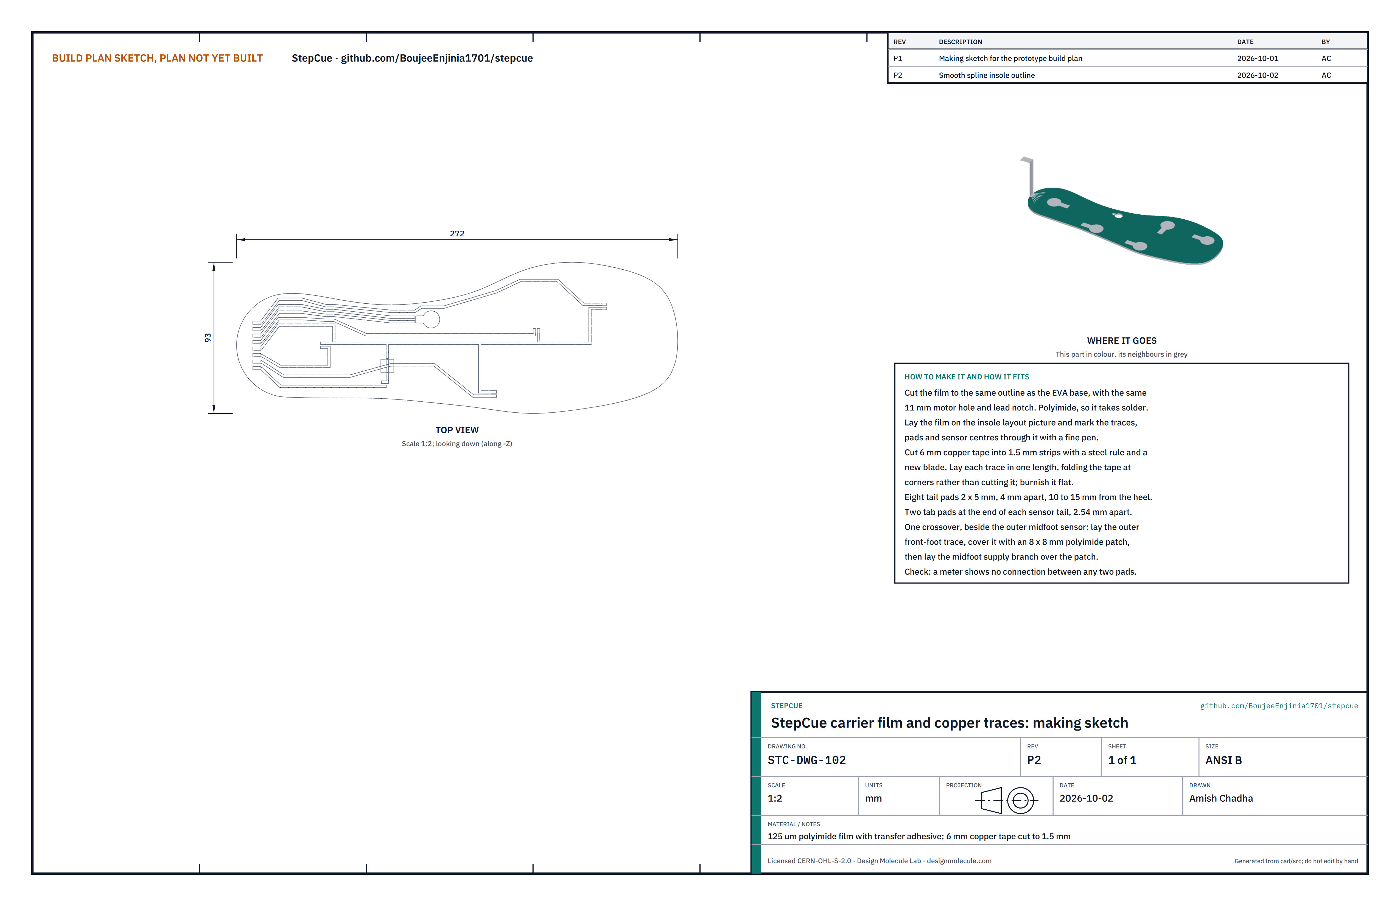
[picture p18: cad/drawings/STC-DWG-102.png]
Figure 3. Making sketch of the carrier film and its traces


*Figure 3. Carrier film and copper traces making sketch (STC-DWG-102).*

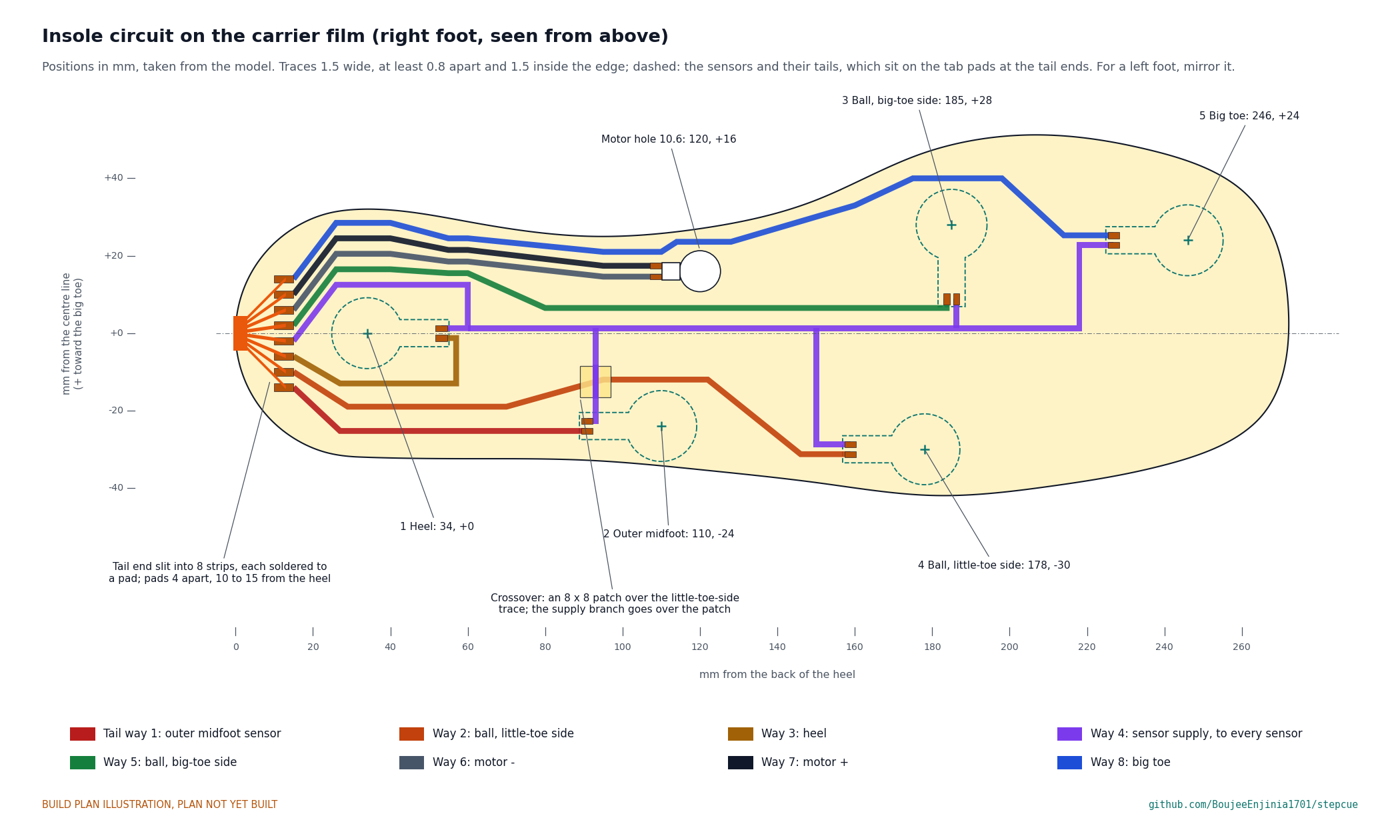
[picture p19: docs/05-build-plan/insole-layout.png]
Figure 4. The insole circuit with every position


*Figure 4. The circuit on the carrier film, seen from above, with the sensor sites, the motor hole and the eight traces. Print it full size and use it as the template.*

**What it is and what it is made from.** A thin film that carries the copper circuit joining the sensors and the motor to the tail. Polyimide film 125 µm thick with a transfer adhesive on its underside; copper foil tape 6 mm wide with conductive adhesive; one small piece of polyimide tape. Polyimide is used because it does not melt under a soldering iron.

**How to make it.**

1. Cut the film to the same outline as the EVA base, with the same motor hole and lead notch.
2. Lay the film over the printed layout (Figure 4) and mark, with a fine pen, the five sensor centres, the eight tail pads at the heel, the two tab pads at each sensor tail, the two motor lead pads and the line of each trace.
3. Cut the copper tape into strips 1.5 mm wide with a steel rule and a new blade. Cut the pads from the same tape: tail pads 2 x 5, tab pads 1.6 x 3 and motor pads 1.5 x 3.
4. Lay each trace in one piece from its pad at the heel to its pad at the sensor. At a corner, fold the tape over itself rather than cutting it, so the trace stays continuous. Burnish each trace flat with the back of a spoon.
5. The supply trace runs up the centre line with a short branch to every sensor. Where the branch to the outer midfoot sensor crosses the trace to the ball of the foot on the little-toe side, lay that lower trace first, cover it with an 8 x 8 mm square of polyimide tape, then lay the branch over the square (Figure 9).
6. Keep every trace at least 0.8 mm from the next, 1.5 mm inside the edge and off the sensor discs, as Figure 4 shows.

**How it fits the parts next to it.** Its underside sticks to the EVA base. The sensors, the tail end and the motor leads are soldered to its pads (sections 3.3 to 3.5); the spacer sticks over it.

**Check before moving on.** With a meter, each trace reads end to end below 1 ohm, and no two pads are connected to each other, including across the crossover.

### 3.3 Pressure sensors (buy 5)

**What they are.** Five round force-sensing resistors, 18.3 mm across and 0.46 mm thick, each with a short flat tail ending in two solder tabs 2.54 mm apart (BOM line 2).

**What to do to them.** Nothing before fitting. Check that each tail and tab spacing matches the tab pads on the carrier; if your sensors have a longer tail, move the tab pads to suit before laying the traces.

**How they fit the parts next to them.** Each sensor lies face up on the carrier at its site with its tail along its tab pads, held by its own adhesive backing, and each tab is soldered to its pad: one to the supply, one to its own trace.

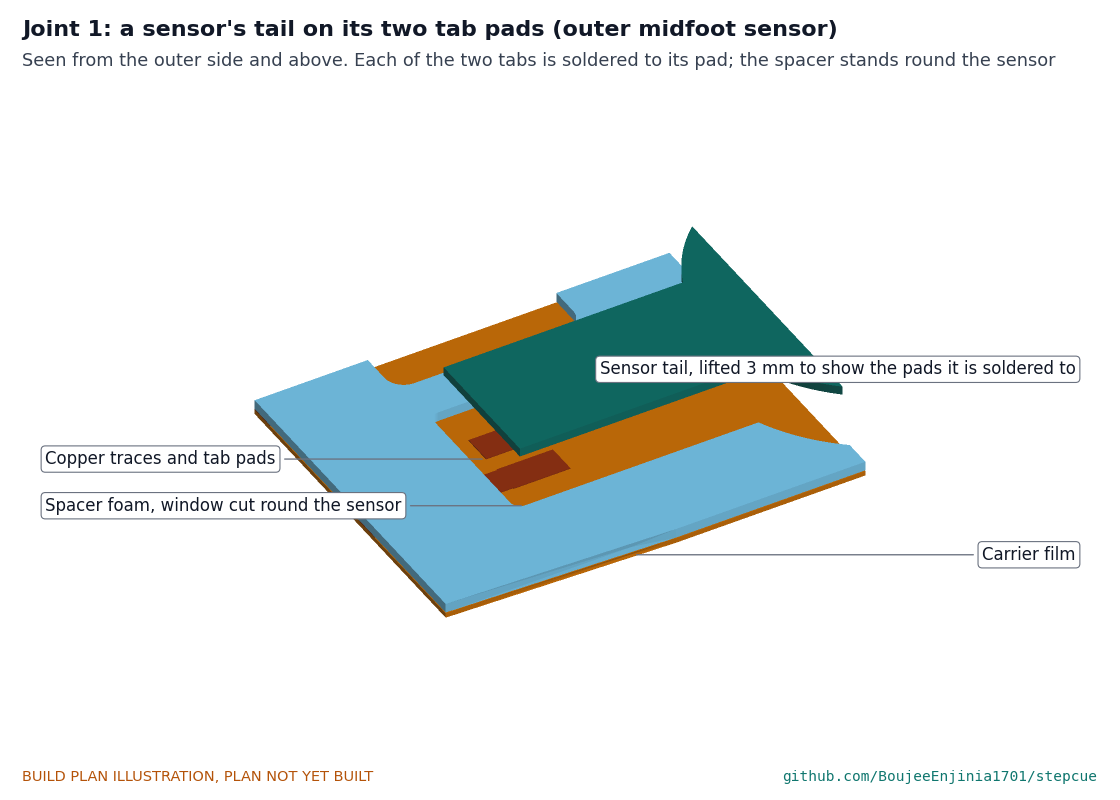
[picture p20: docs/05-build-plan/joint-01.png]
Figure 5. Joint 1: a sensor's tail on its two tab pads


*Figure 5. The tail of the outer midfoot sensor, drawn lifted 3 mm so the two tab pads under it show; the spacer foam has a window round the whole sensor.*

**Check before moving on.** Pressing the sensor with a finger changes its resistance, read at its pad at the heel and the supply pad, from several hundred kilohms or more to a few kilohms.

### 3.4 Flex tail (buy 1)

**What it is.** An 8-way flat flex cable with a 1.0 mm pitch, 9 mm wide and 0.3 mm thick, about 100 mm long, with tinned ends on the same side (BOM line 4).

**What to do to it.** At one end, slit the cable lengthwise between its conductors for the last 10 mm with a new blade against a steel rule, making eight strips. Leave the other end whole for the connector.

**How it fits the parts next to it.** The strips fan out onto the eight tail pads at the heel and each bare end is soldered to its pad. The full-width part runs back over the heel edge, turns up the inside of the heel counter under the clip, crosses the counter's top and enters the pod (section 3.8).

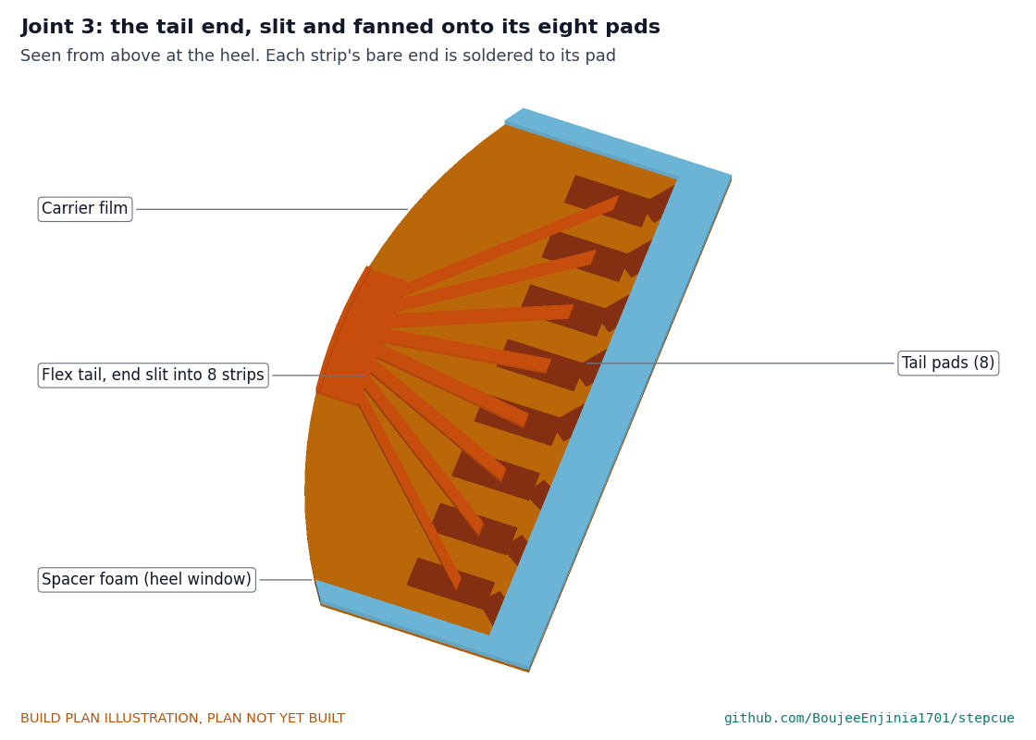
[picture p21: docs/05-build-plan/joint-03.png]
Figure 6. Joint 3: the tail end slit and fanned onto its pads


*Figure 6. Each strip of the tail lies on its own pad.*

**Check before moving on.** Each conductor reads below 1 ohm from its pad to the far end of the tail, and no two strips touch.

### 3.5 Vibration motor (buy 1)

**What it is.** A 10 mm coin vibration motor, 2.7 mm thick, 3 V, with an adhesive face and two flying leads (BOM line 5).

**What to do to it.** Shorten the leads to about 8 mm and tin their ends.

**How it fits the parts next to it.** It stands in the motor hole, adhesive face up, with its leads up through the notch onto the two motor pads. Its top face sticks to the underside of the spacer; its bottom stands 0.1 mm clear of the shoe's floor, under 1.7 mm of foam.

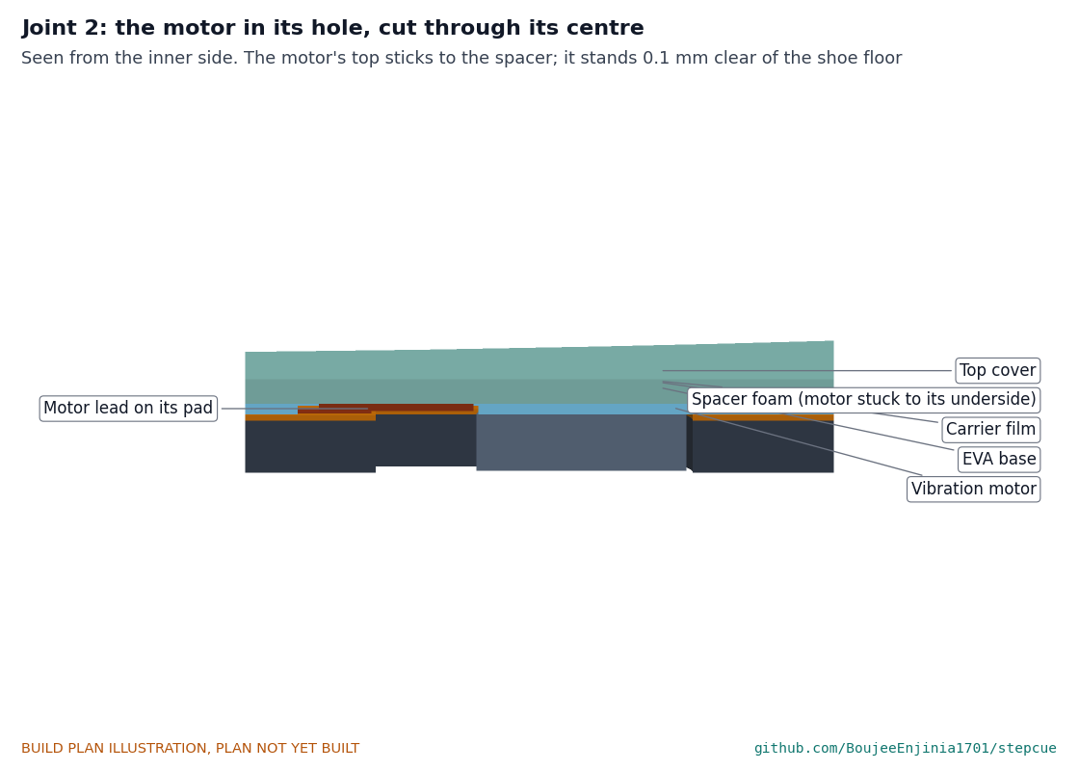
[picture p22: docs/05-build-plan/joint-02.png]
Figure 7. Joint 2: the motor in its hole


*Figure 7. Cut through the motor's centre: base, carrier, motor, spacer and cover.*

**Check before moving on.** With 3 V from a bench supply through the two motor pads (current limit 100 mA), the motor runs; its top is level with the carrier surface, not above it.

### 3.6 Spacer foam

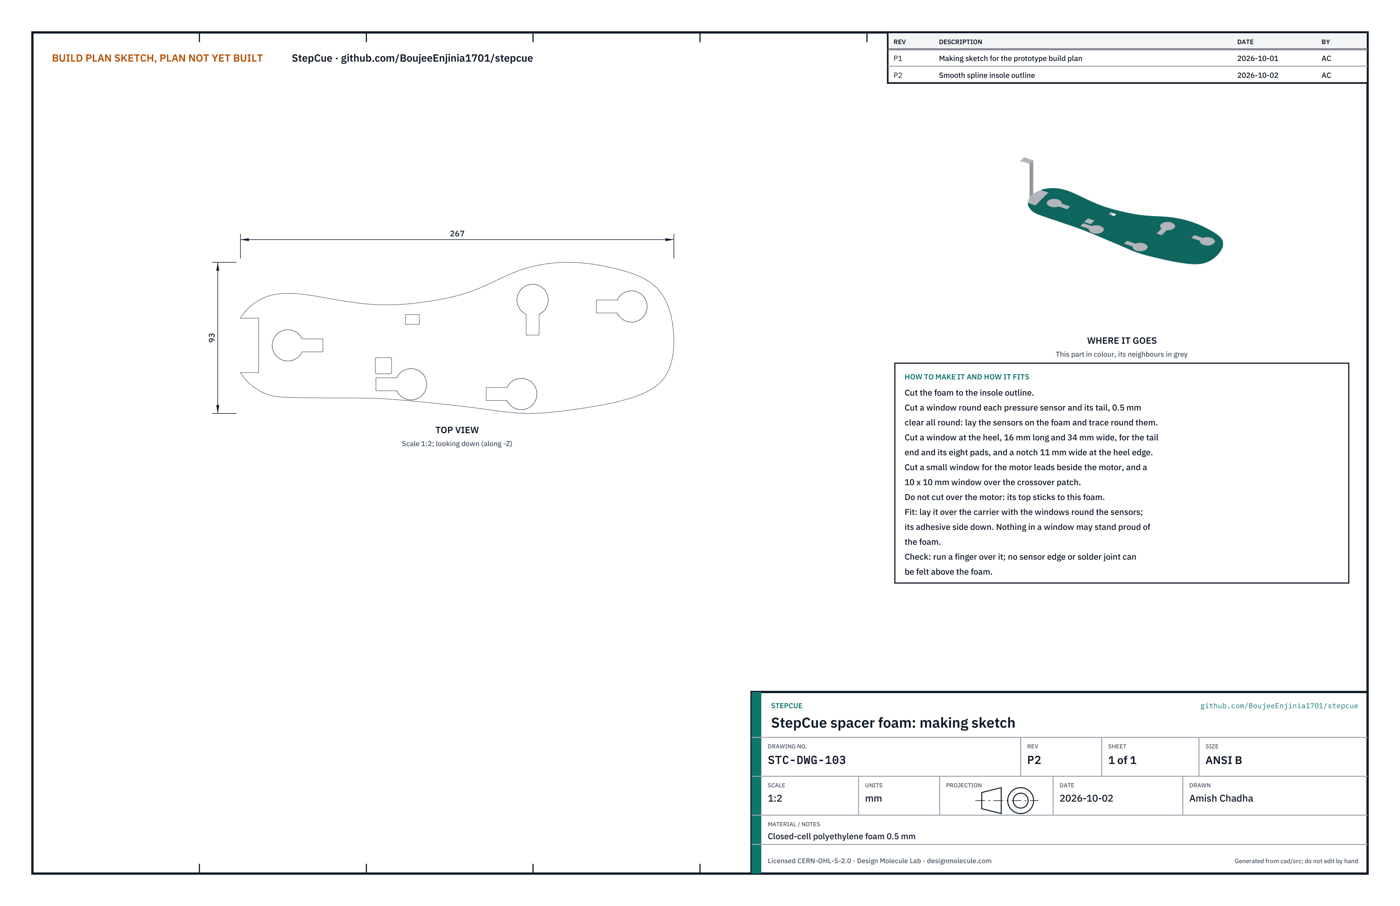
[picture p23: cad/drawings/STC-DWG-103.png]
Figure 8. Making sketch of the spacer foam


*Figure 8. Spacer foam making sketch (STC-DWG-103).*

**What it is and what it is made from.** The layer that fills the space round the sensors so the cover lies flat. Closed-cell polyethylene foam 0.5 mm thick (BOM line 14), with an adhesive underside or a spray of contact adhesive.

**How to make it.**

1. Cut the foam to the insole outline.
2. Lay the five sensors on it at their sites and trace round each sensor and its tail; cut each window 0.5 mm outside the line.
3. Cut a window at the heel 16 mm long and 34 mm wide for the tail end and its pads, and an 11 mm wide notch at the heel edge.
4. Cut a small window beside the motor for its leads and pads, and a 10 x 10 mm window over the crossover patch. Do not cut over the motor itself.

**How it fits the parts next to it.** It sticks down over the carrier with the windows round the sensors, the tail pads, the leads and the patch, and presses onto the motor's adhesive face.

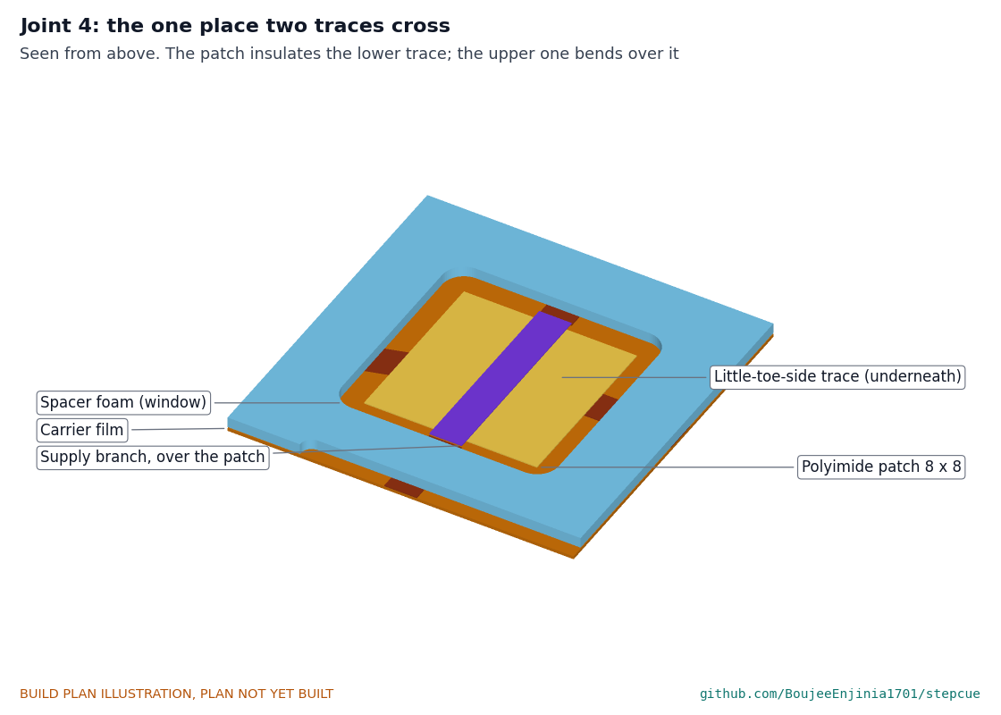
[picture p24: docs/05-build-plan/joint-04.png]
Figure 9. Joint 4: the crossover


*Figure 9. The one crossover: the lower trace, the polyimide patch over it, the supply branch over the patch, and the spacer window round them.*

**Check before moving on.** Run a finger over the surface: no sensor edge, solder joint or lead can be felt above the foam.

### 3.7 Top cover

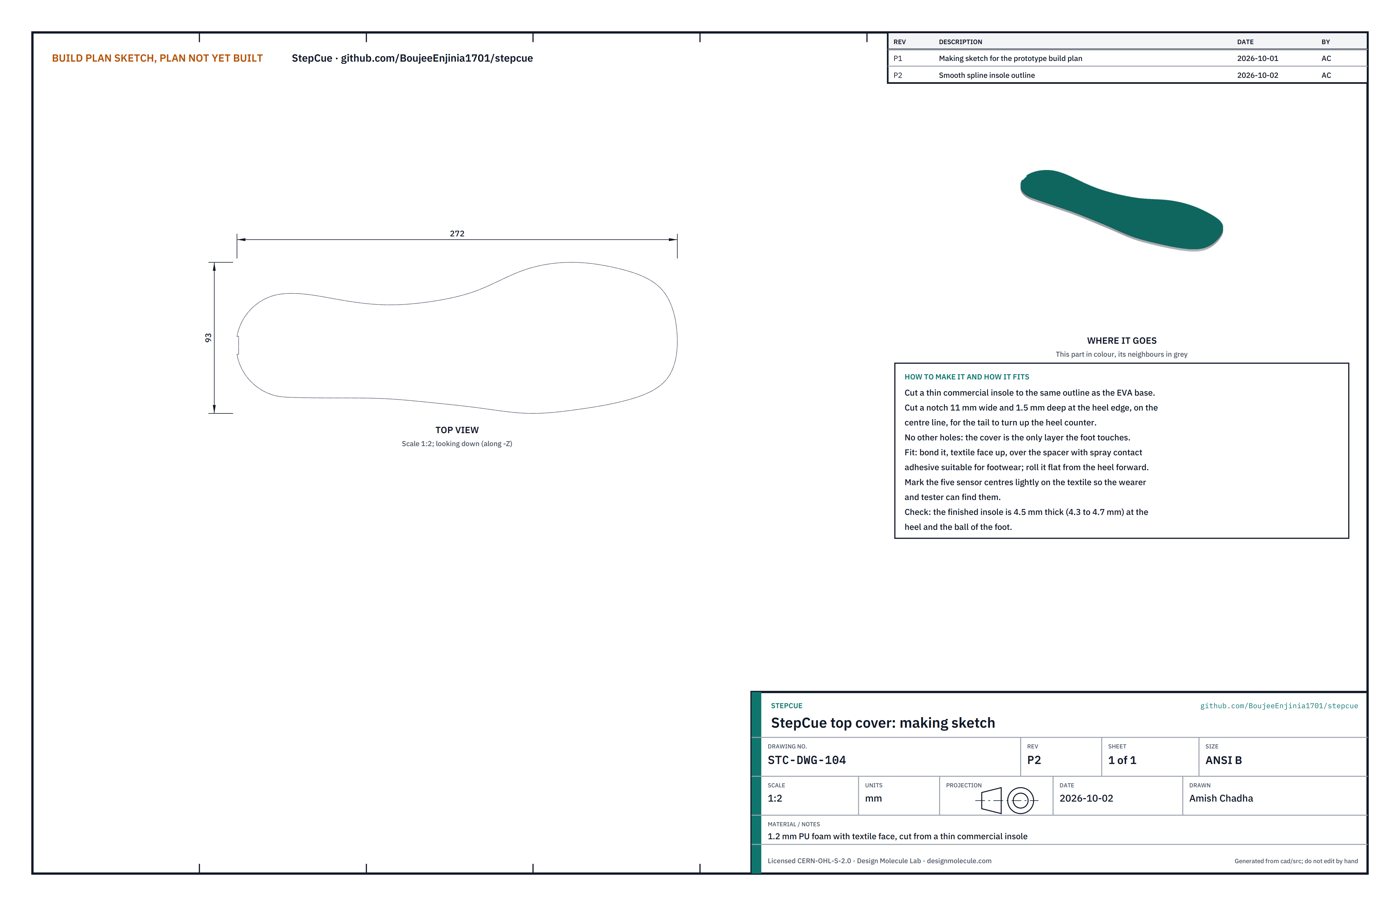
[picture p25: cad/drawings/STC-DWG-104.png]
Figure 10. Making sketch of the top cover


*Figure 10. Top cover making sketch (STC-DWG-104).*

**What it is and what it is made from.** The layer the foot touches. A thin commercial insole of 1.2 mm polyurethane foam with a textile face (BOM line 1).

**How to make it.**

1. Cut the insole to the same outline.
2. Cut an 11 mm wide notch, 1.5 mm deep, at the heel edge on the centre line.
3. Mark the five sensor centres lightly on the textile.

**How it fits the parts next to it.** It is bonded textile face up over the spacer with a contact adhesive made for footwear, rolled on from the heel forward, with the notch over the tail.

**Check before moving on.** The finished insole is 4.5 mm thick (4.3 to 4.7 mm) at the heel and at the ball of the foot, and flat with no bumps over the sensors.

### 3.8 Pod base with clip

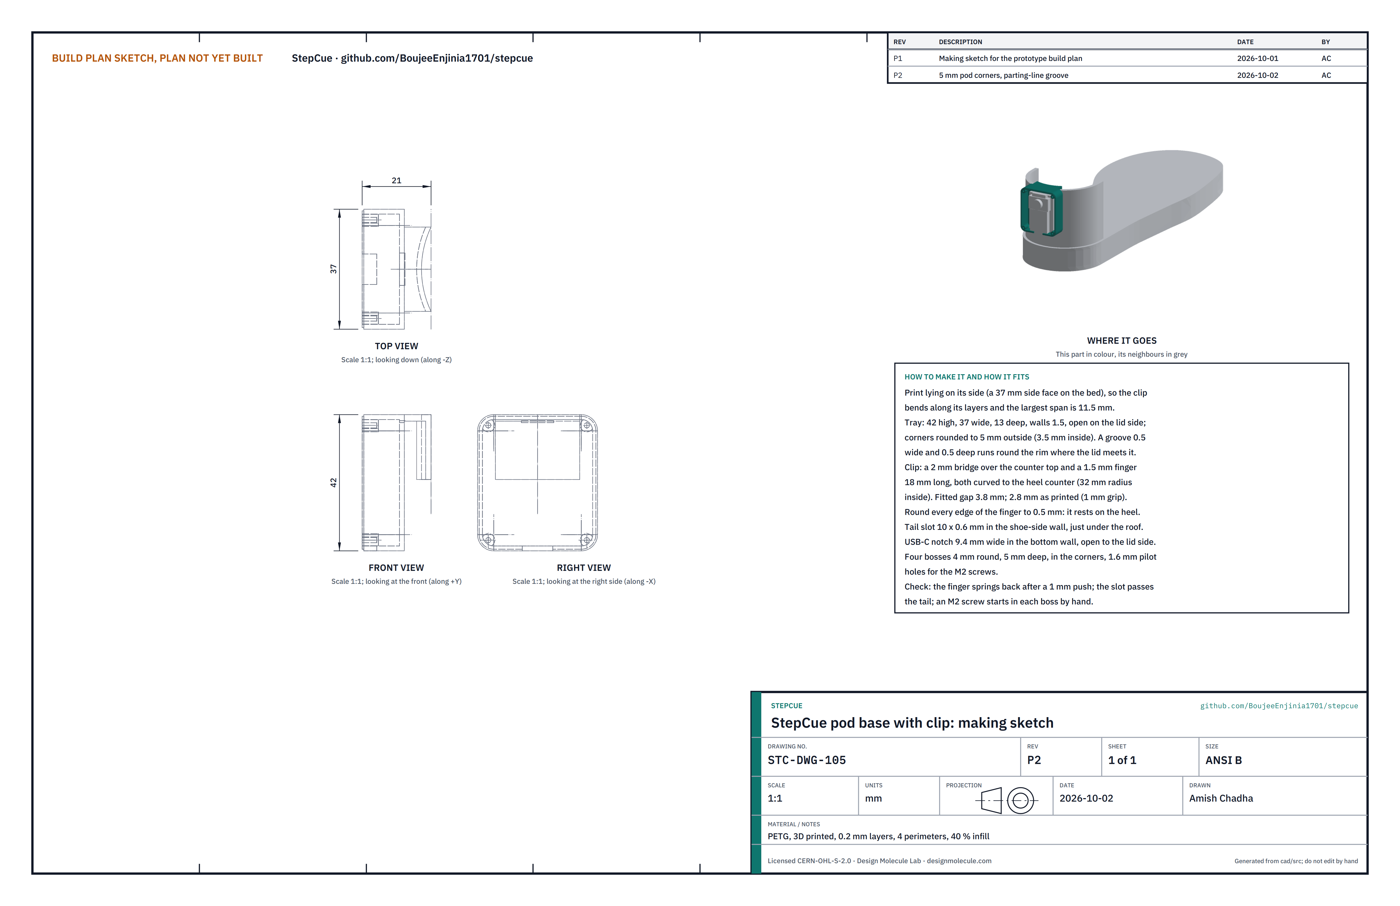
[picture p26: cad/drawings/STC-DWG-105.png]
Figure 11. Making sketch of the pod base


*Figure 11. Pod base making sketch (STC-DWG-105).*

**What it is and what it is made from.** The tray that holds the electronics and the clip that hooks it over the heel counter. PETG, 3D printed.

**How to make it.**

1. Print it lying on one of its 37 mm side faces, at 0.2 mm layers, four perimeters and 40 % infill. In this position the clip bends along its layers, not across them, and the widest span the printer must bridge is 11.5 mm.
2. The tray is 42 high, 37 wide and 13 deep with 1.5 mm walls, open on the lid side. Its four long edges are rounded to 5 mm outside and 3.5 mm inside, so the wall stays 1.5 mm thick round the corners. A groove 0.5 mm wide and 0.5 mm deep runs round the rim where the lid meets it.
3. The clip is a 2 mm bridge over the counter top and a 1.5 mm finger 18 mm long and 26 mm wide, both curved to the counter (32 mm radius inside). As printed, the gap between the finger and the tray is 1 mm narrower than the counter and tail together, so the clip grips.
4. Round every edge of the finger to about 0.5 mm with a fine file: it rests against the wearer's heel through the sock.
5. Clear the tail slot (10 x 0.6 mm, in the shoe-side wall just under the roof), the USB-C notch (9.4 mm wide in the bottom wall) and the four 1.6 mm pilot holes in the corner bosses.

**How it fits the parts next to it.** Its flat shoe-side face rests on the outside of the heel counter at the heel centre; the bridge rides over the counter's top and the tail, and the finger presses the tail against the inside of the counter.

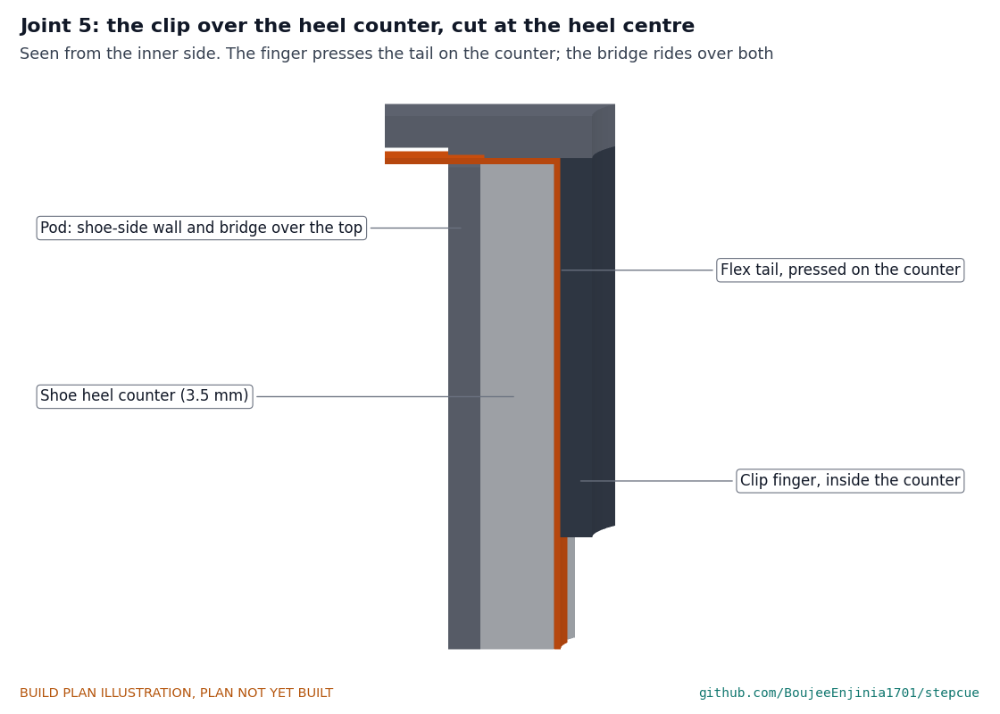
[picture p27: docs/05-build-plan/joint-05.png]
Figure 12. Joint 5: the clip over the heel counter


*Figure 12. Cut at the heel centre: the pod's shoe-side wall outside the counter, the bridge over its top, and the finger inside pressing the tail flat on the counter.*

**Check before moving on.** The finger springs back after a 1 mm push; the tail slides through the slot; an M2 screw starts in each boss by hand.

### 3.9 Cell (buy 1)

**What it is.** A 400 mAh, 3.7 V lithium polymer cell about 35 x 25 x 5 mm (502535 class) with built-in protection and a lead (BOM line 8).

**What to do to it.** Check its voltage (3.6 to 4.1 V) and that it is flat and undamaged. Keep it on the charging spot of safety stop S2 until step 9, and unplugged until safety stop S3.

**How it fits the parts next to it.** It stands against the inside of the shoe-side wall, on 0.3 mm double-sided tape down its middle, leads at the bottom.

### 3.10 Controller module (buy 1)

**What it is.** A thumbnail-sized nRF52840 board with a motion sensor, charger and USB-C on board (XIAO nRF52840 Sense class, BOM line 9).

**What to do to it.** Solder a short 2-pin JST-PH lead, to mate with the cell's plug, to its battery pads (the pads on the underside), and insulate the joints with polyimide tape. The cell stays unplugged. Solder the wires to the interface board (section 3.11).

**How it fits the parts next to it.** It sits on the cell's outer face, held by 0.5 mm double-sided foam tape, USB-C downward with the receptacle standing in the notch in the bottom wall.

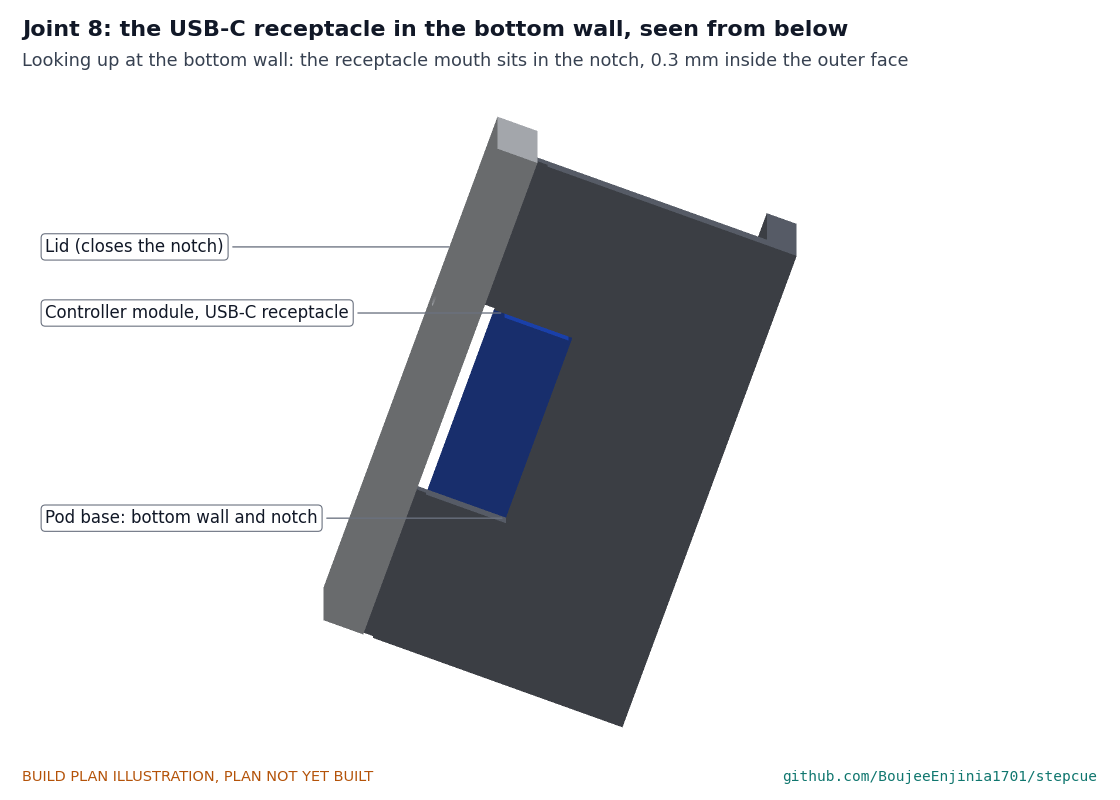
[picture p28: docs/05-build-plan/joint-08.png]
Figure 13. Joint 8: the USB-C receptacle in the bottom wall


*Figure 13. Looking up at the bottom wall: the receptacle in its notch, closed on the lid side by the lid.*

**Check before moving on.** A USB-C cable plugs in fully and the module's power light comes on (cell disconnected).

### 3.11 Interface board with the tail connector and button cap

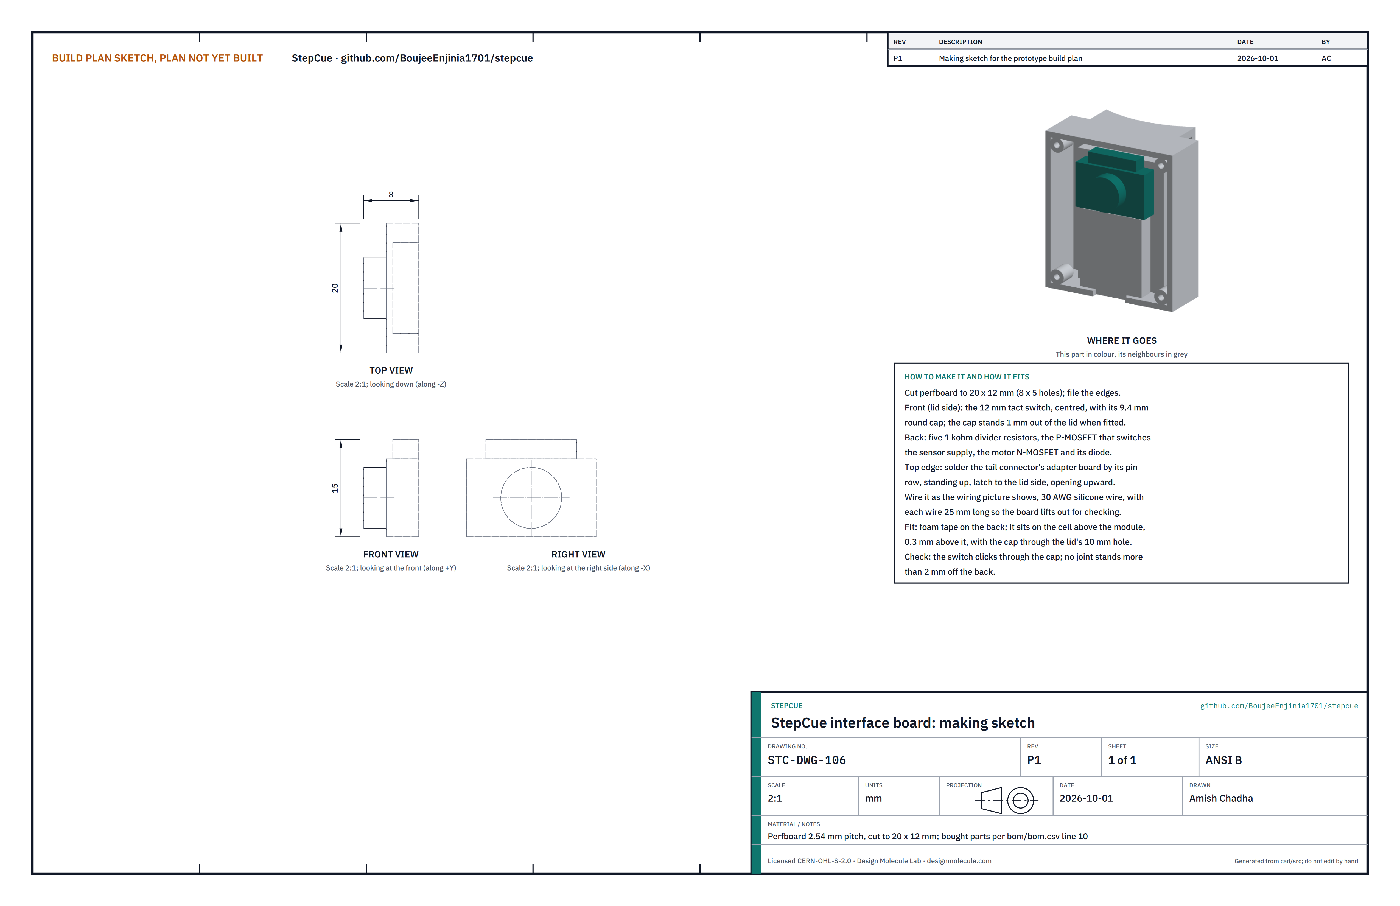
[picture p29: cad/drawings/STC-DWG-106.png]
Figure 14. Making sketch of the interface board


*Figure 14. Interface board making sketch (STC-DWG-106).*

**What it is and what it is made from.** A small hand-wired board that powers the sensors only while it reads them, drives the motor and carries the pause button and the tail connector. Perfboard with 2.54 mm hole spacing; parts per BOM lines 10 and 13.

**How to make it.**

1. Cut the perfboard to 20 x 12 mm (8 x 5 holes) and file the edges.
2. On the front (lid side), fit the 12 mm tact switch in the centre and press its 9.4 mm round cap on.
3. On the back, fit the five 1 kohm resistors, the P-MOSFET that switches the sensor supply, and the motor N-MOSFET with its diode across the motor pins.
4. Solder the tail connector's adapter board to the top edge by its pin row, standing up, opening upward and latch toward the lid.
5. Wire it as Figure 15 shows with 30 AWG silicone wire, each wire about 25 mm long so the board can be lifted out for checking.

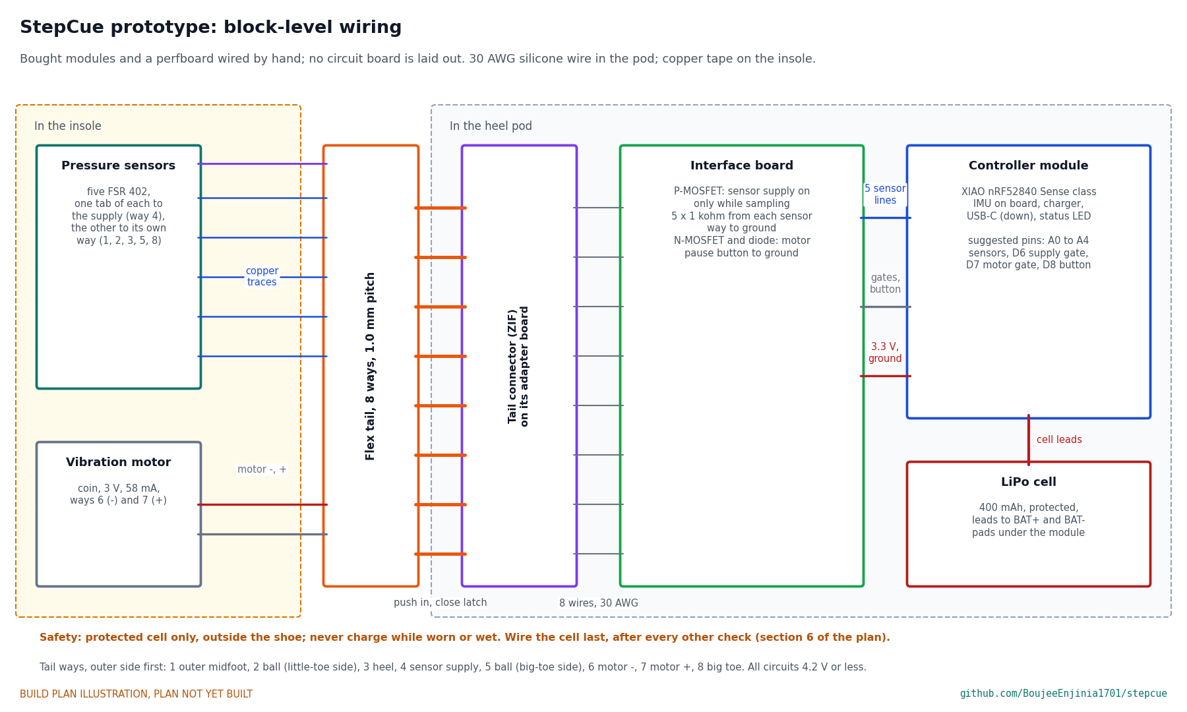
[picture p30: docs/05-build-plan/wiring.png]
Figure 15. Block-level wiring


*Figure 15. Block-level wiring. No circuit board is laid out; the controller pins shown are suggestions to be set in the firmware.*

**How it fits the parts next to it.** It sits on the cell's outer face, just above the module, on 0.5 mm foam tape. The tail drops into its connector from above, and the button cap passes through the lid.

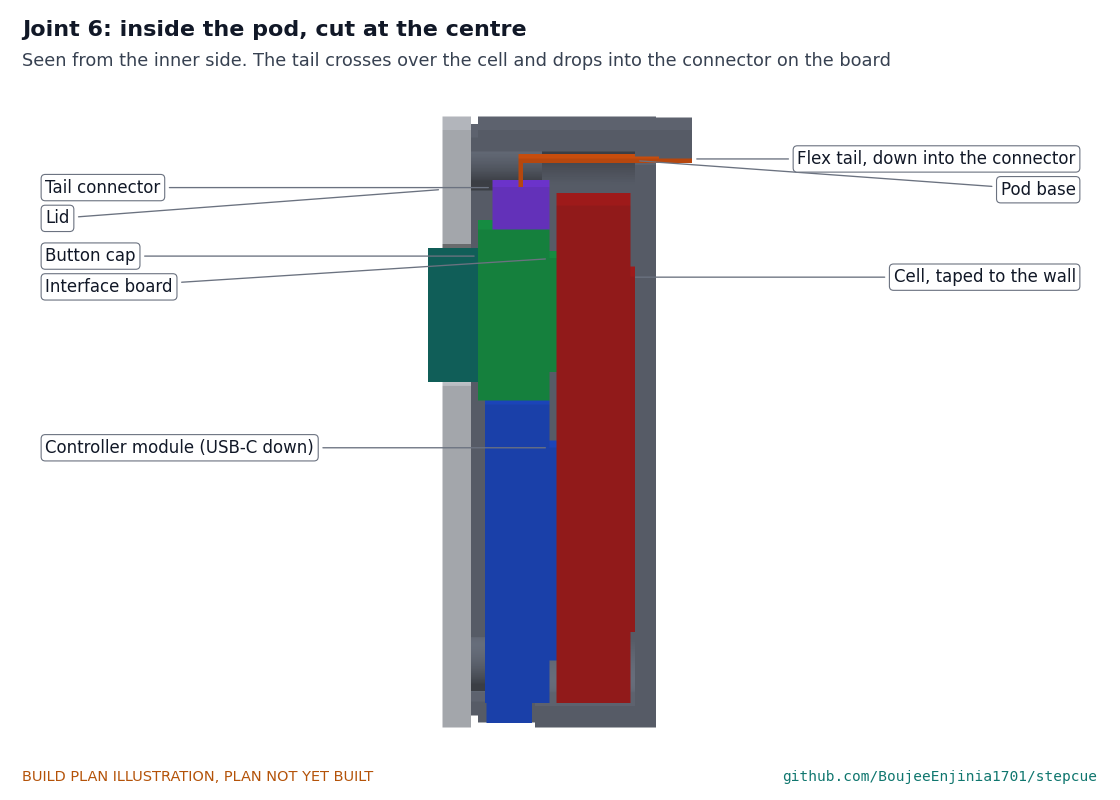
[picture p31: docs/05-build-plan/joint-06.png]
Figure 16. Joint 6: inside the pod


*Figure 16. Cut at the centre: cell against the wall, module below, interface board and connector above, the tail crossing over the cell into the connector.*

**Check before moving on.** The switch clicks through the cap; no joint stands more than 2 mm off the back; with a meter, every one of the eight connector ways reaches the right point on the board.

### 3.12 Lid

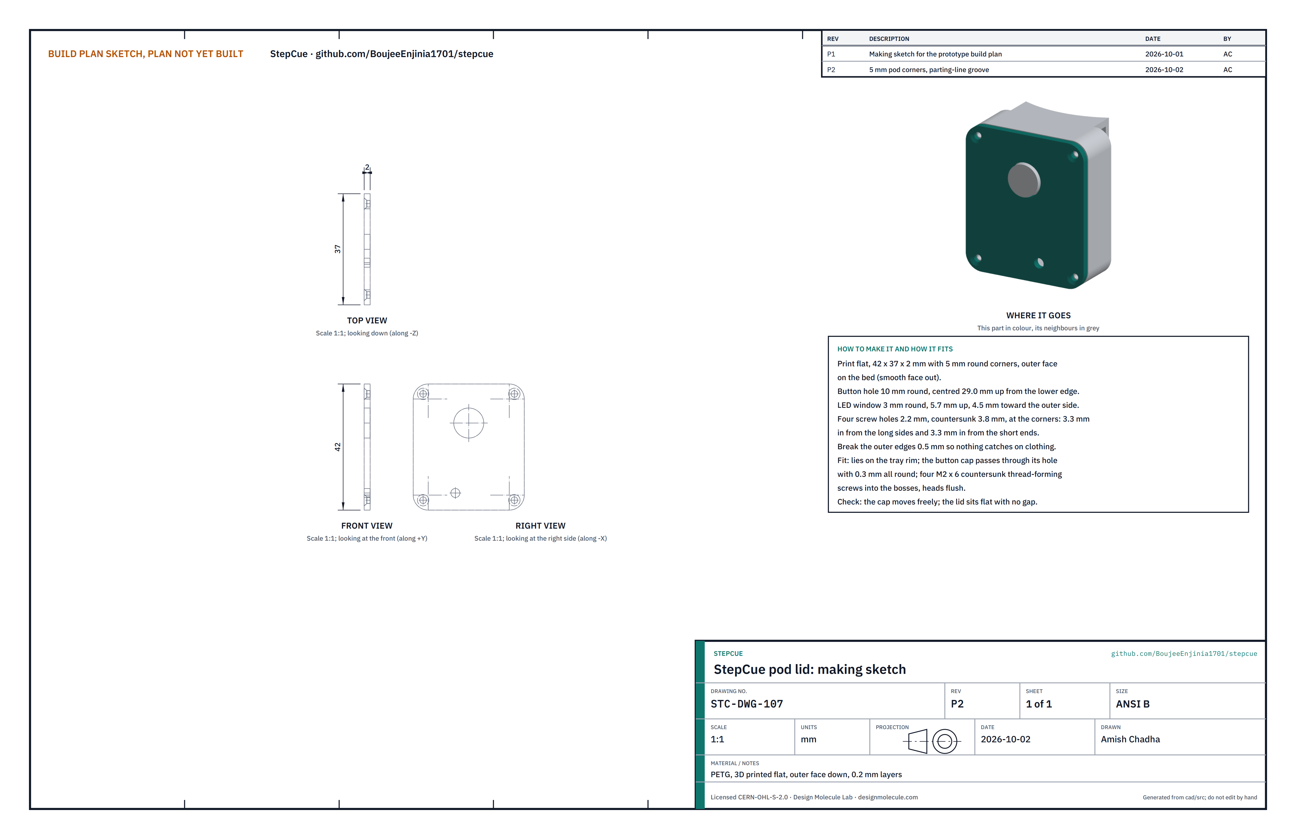
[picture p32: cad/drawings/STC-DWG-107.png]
Figure 17. Making sketch of the lid


*Figure 17. Lid making sketch (STC-DWG-107).*

**What it is and what it is made from.** The flat cover of the pod. PETG, 3D printed, 42 x 37 x 2 mm, with its corners rounded to 5 mm to match the base.

**How to make it.**

1. Print it flat with its outer face on the bed, so the outside is smooth.
2. Clear the 10 mm button hole, the 3 mm LED window and the four 2.2 mm screw holes; countersink the screw holes to 3.8 mm.
3. Break the outer edges by about 0.5 mm so nothing catches on clothing.

**How it fits the parts next to it.** It lies on the tray's rim and closes the USB-C notch. Four M2 x 6 countersunk thread-forming screws go through it into the corner bosses, heads flush.

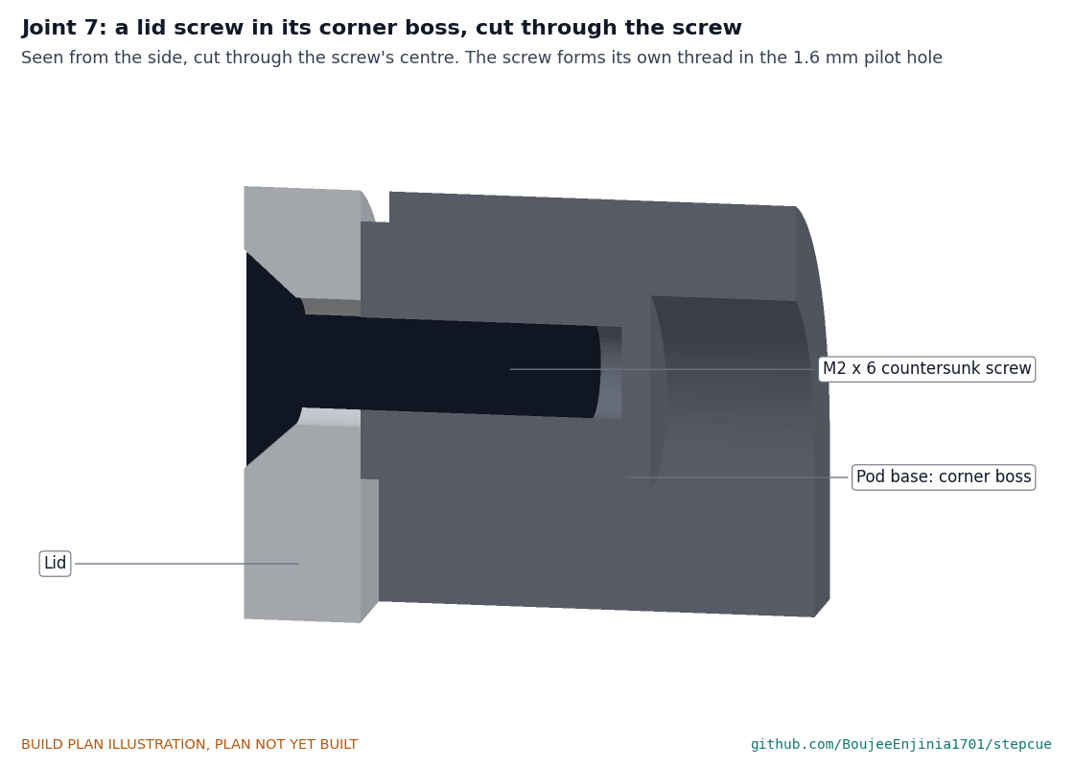
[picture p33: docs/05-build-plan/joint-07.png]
Figure 18. Joint 7: a lid screw in its boss


*Figure 18. Cut through the screw: its head sits flush in the lid's countersink and it cuts its own thread in the 1.6 mm pilot hole.*

**Check before moving on.** The lid sits flat on the rim with no gap, and the button cap moves freely in its hole.

### 3.13 Bought components

Buy to specification, not brand. Line numbers are those of the bill of materials.

- **Top cover (line 1).** A thin insole, 1.2 mm polyurethane foam with a textile face.
- **Pressure sensors (line 2).** Five force-sensing resistors, 18.3 mm round, 0.46 mm thick, 0.2 to 20 N, short tail with two solder tabs 2.54 mm apart.
- **Carrier materials (line 3).** Polyimide film 125 µm with transfer adhesive; copper foil tape 6 mm with conductive adhesive; polyimide tape.
- **Flex tail (line 4).** 8-way, 1.0 mm pitch flat flex cable, 9 mm wide, about 100 mm, tinned ends on the same side.
- **Vibration motor (line 5).** 10 mm coin motor, 2.7 mm thick, 3 V, about 60 mA, adhesive face.
- **EVA base (line 6).** EVA foam sheet 2.5 mm.
- **Cell (line 8).** 400 mAh, 3.7 V lithium polymer, about 35 x 25 x 5 mm, with built-in protection.
- **Controller module (line 9).** nRF52840 board with a six-axis motion sensor, six analog inputs, a charger and USB-C, about 21 x 18 mm.
- **Interface board parts (line 10).** Perfboard; five 1 kohm resistors; a logic-level P-MOSFET and N-MOSFET; a small diode; a 12 mm tact switch with a round cap about 9.4 mm across.
- **Hardware (line 12).** Four M2 x 6 countersunk thread-forming screws; 0.3 mm double-sided transfer tape and 0.5 mm double-sided foam tape; polyimide tape; 30 AWG silicone wire; solder; heat-shrink.
- **Tail connector (line 13).** 8-way, 1.0 mm pitch ZIF connector for flat flex cable, on a small adapter board with 2.54 mm pins.
- **Spacer foam (line 14).** Closed-cell polyethylene foam sheet 0.5 mm.

## 4. Putting it together

In each picture the parts already fitted are grey and the part being fitted is in colour, with an arrow showing the way it goes in. The insole layers are shown pulled up from the bench; the pod parts slide into the tray from its open side.

### Step 1: EVA base on the bench

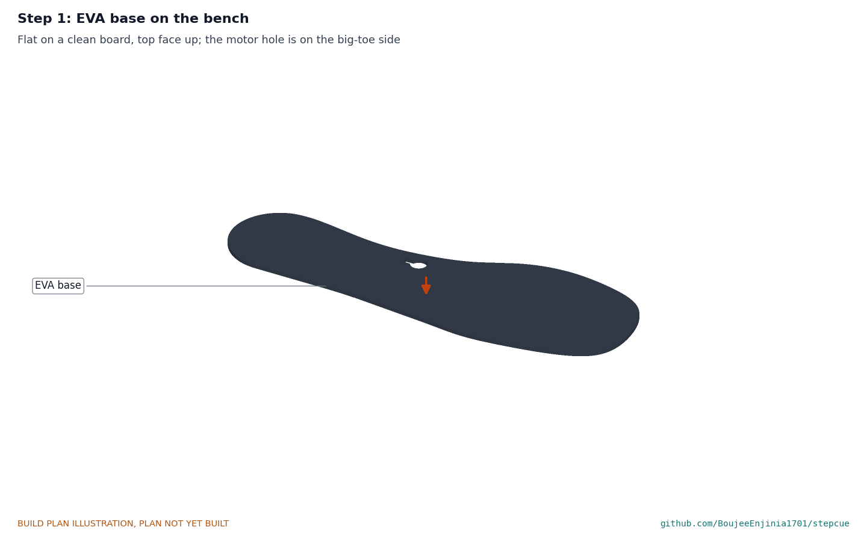
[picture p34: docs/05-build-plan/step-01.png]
Step 1


Lay the base flat on a clean board, top face up.

### Step 2: carrier film onto the base

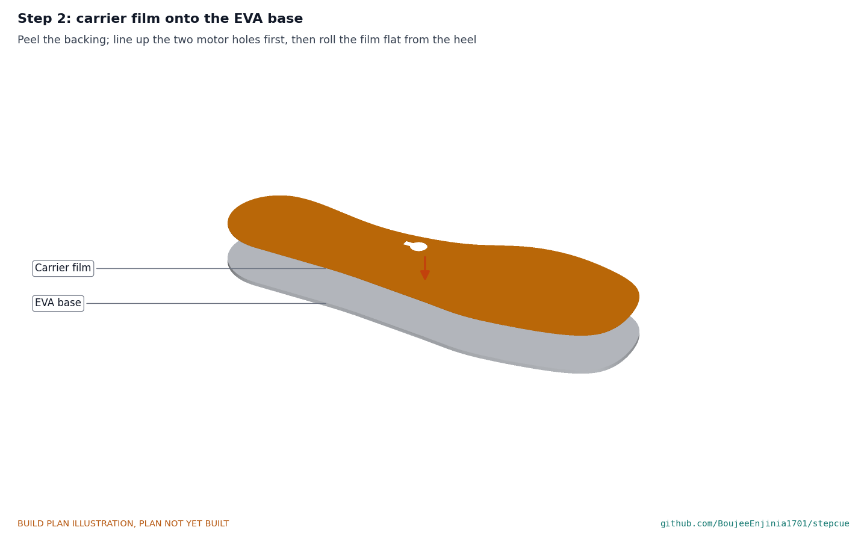
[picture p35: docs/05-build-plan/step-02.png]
Step 2


Peel the film's backing. Line up the two motor holes first, then lower the film from the heel forward and roll it flat.

### Step 3: copper traces, pads and the crossover

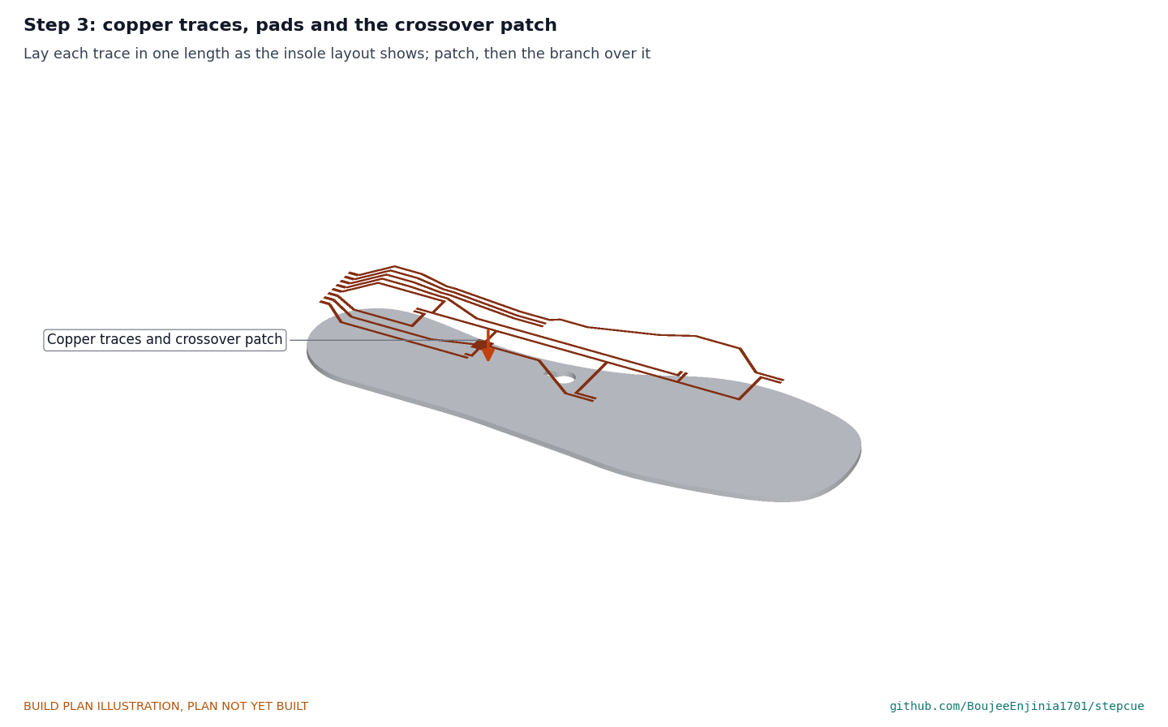
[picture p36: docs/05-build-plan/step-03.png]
Step 3


Lay the circuit as section 3.2 describes. **Hold point:** the continuity checks of section 3.2 pass.

### Step 4: pressure sensors

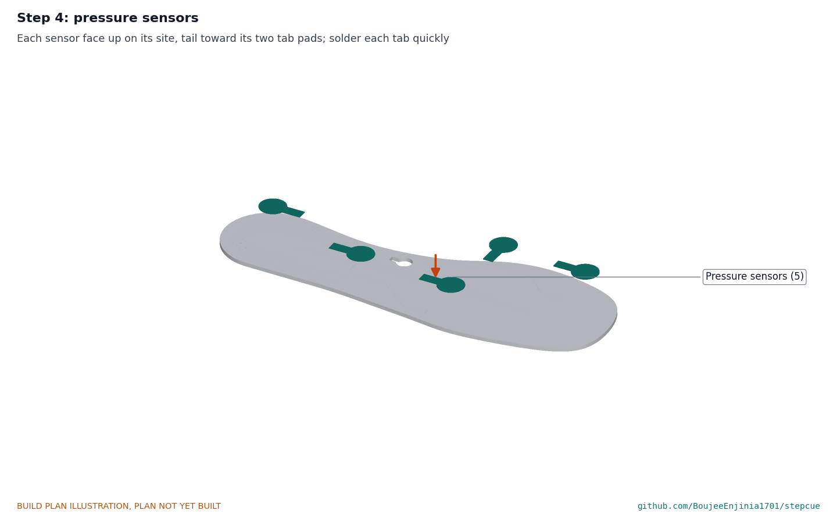
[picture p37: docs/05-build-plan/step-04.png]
Step 4


Peel each sensor's backing and place it face up on its site, tail along its tab pads. Solder each tab to its pad quickly with a fine tip at the lowest temperature that wets the joint (about 300 °C), no more than 3 s per tab, so the sensor's film is not damaged.

### Step 5: flex tail end onto its pads

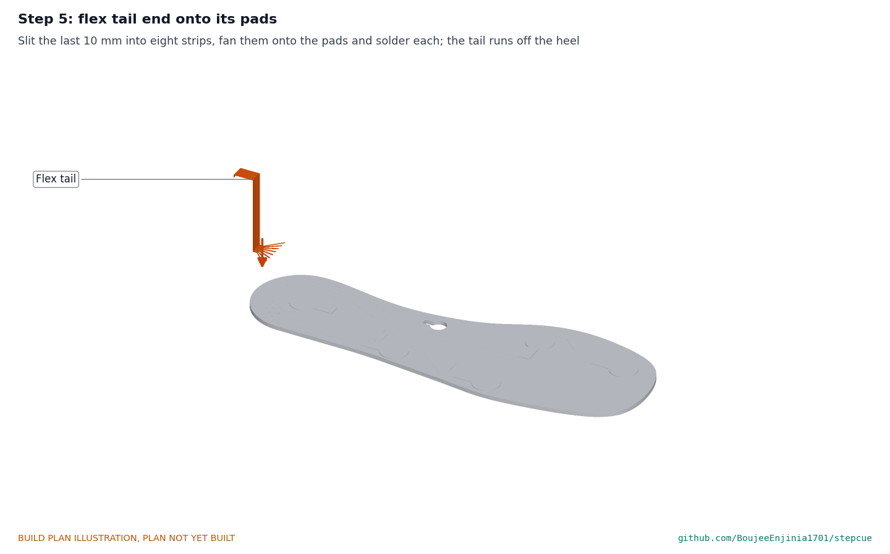
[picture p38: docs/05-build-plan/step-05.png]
Step 5


Fan the eight strips onto the eight pads in order (way 1 on the little-toe side) and solder each. The whole tail runs off the back of the heel.

### Step 6: vibration motor into its hole

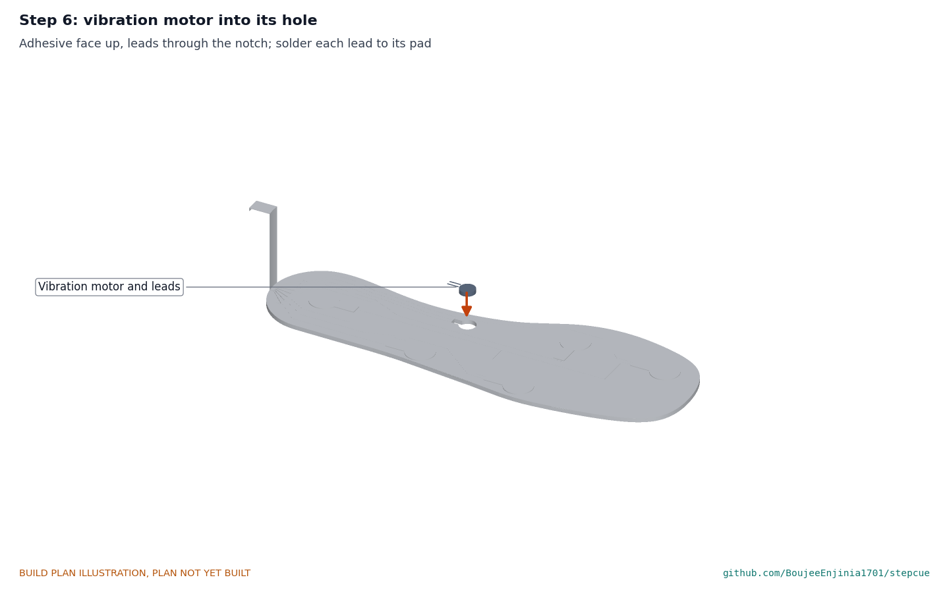
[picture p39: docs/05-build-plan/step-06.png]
Step 6


Drop the motor into its hole adhesive face up, leads through the notch, and solder each lead to its pad. Peel the motor's adhesive liner.

### Step 7: spacer foam

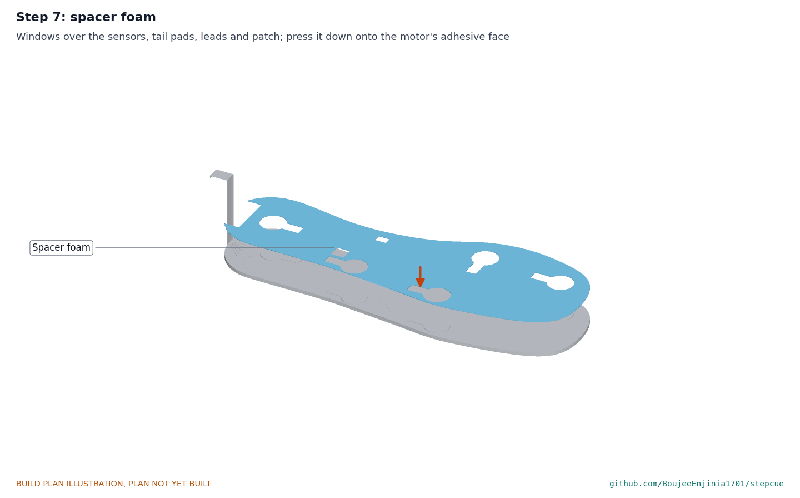
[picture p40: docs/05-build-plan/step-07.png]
Step 7


Lay the spacer from the heel forward with its windows round the sensors, the tail pads, the leads and the patch, and press it down over the motor so the motor's top sticks to it. **Hold point:** the sensor and motor checks of sections 3.3 and 3.5 pass again, read from the far end of the tail.

### Step 8: top cover

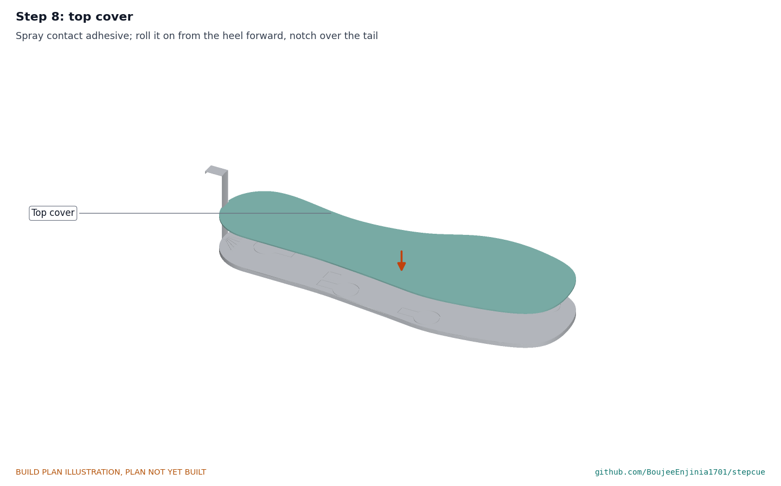
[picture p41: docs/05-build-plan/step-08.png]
Step 8


Spray the spacer and the cover with contact adhesive, let it go tacky, and roll the cover on from the heel forward with its notch over the tail.

### Step 9: cell into the pod base

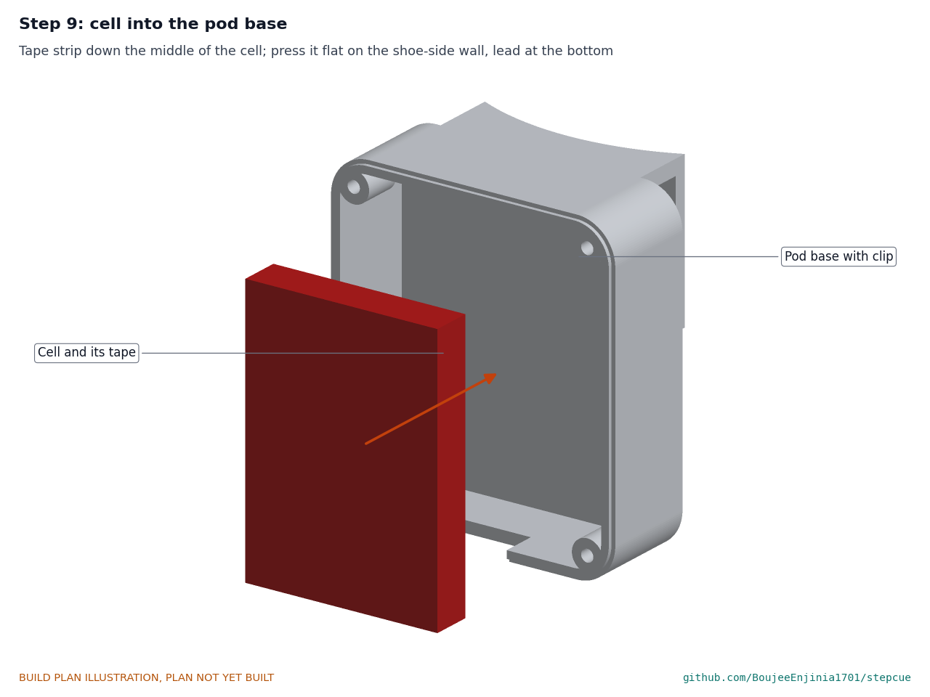
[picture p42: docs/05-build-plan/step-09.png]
Step 9


Only after safety stop S2, with the cell unplugged. Tape down the middle of the cell; press it flat on the inside of the shoe-side wall, lead at the bottom.

### Step 10: controller module

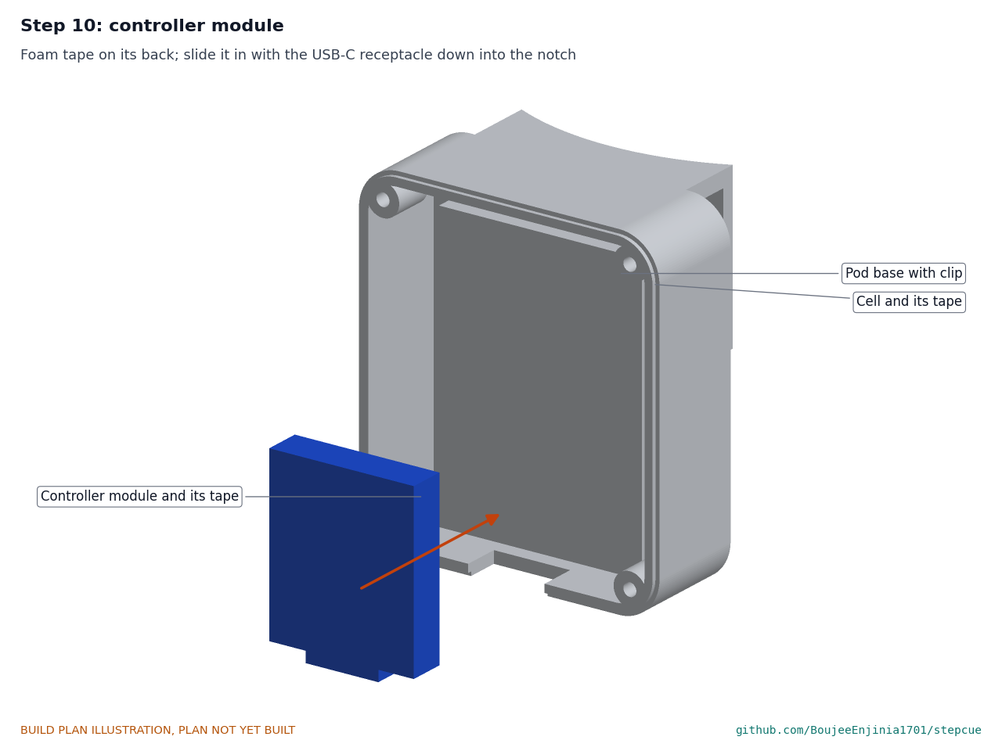
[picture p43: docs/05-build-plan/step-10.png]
Step 10


Foam tape on the module's back; slide it in from the open side with the USB-C receptacle down into its notch.

### Step 11: interface board with the connector and button cap

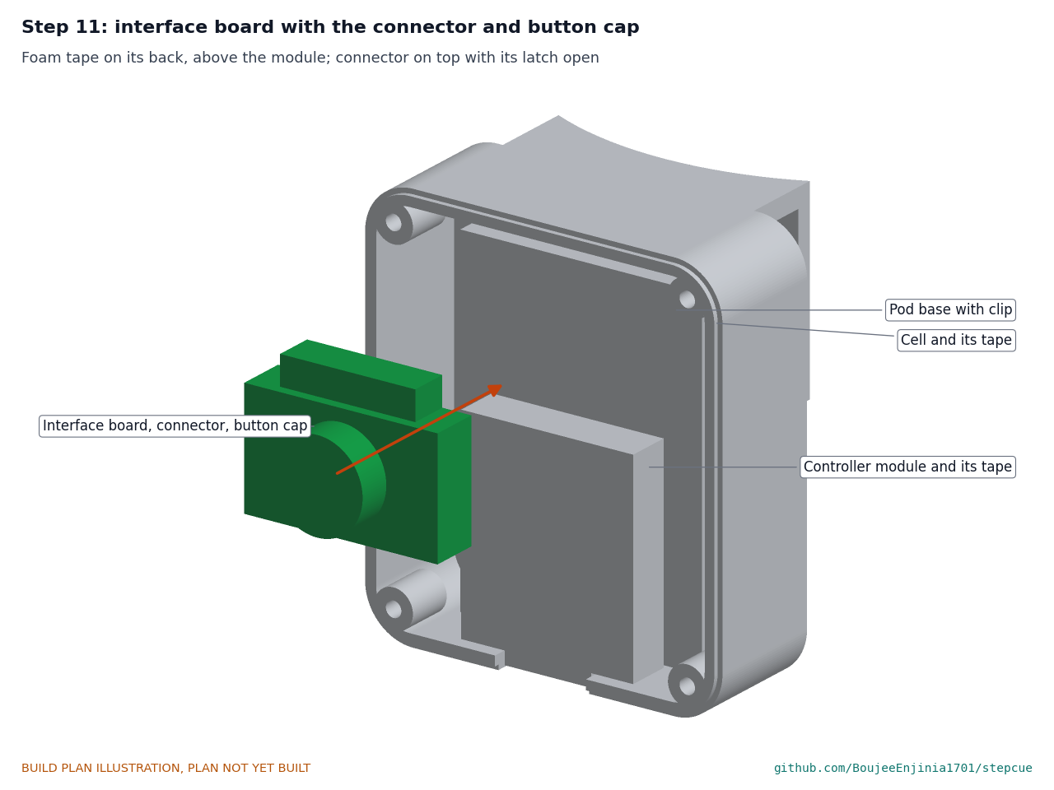
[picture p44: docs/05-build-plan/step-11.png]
Step 11


Foam tape on the board's back; place it above the module with the connector on top and its latch open.

### Step 12: tail into the pod and its connector

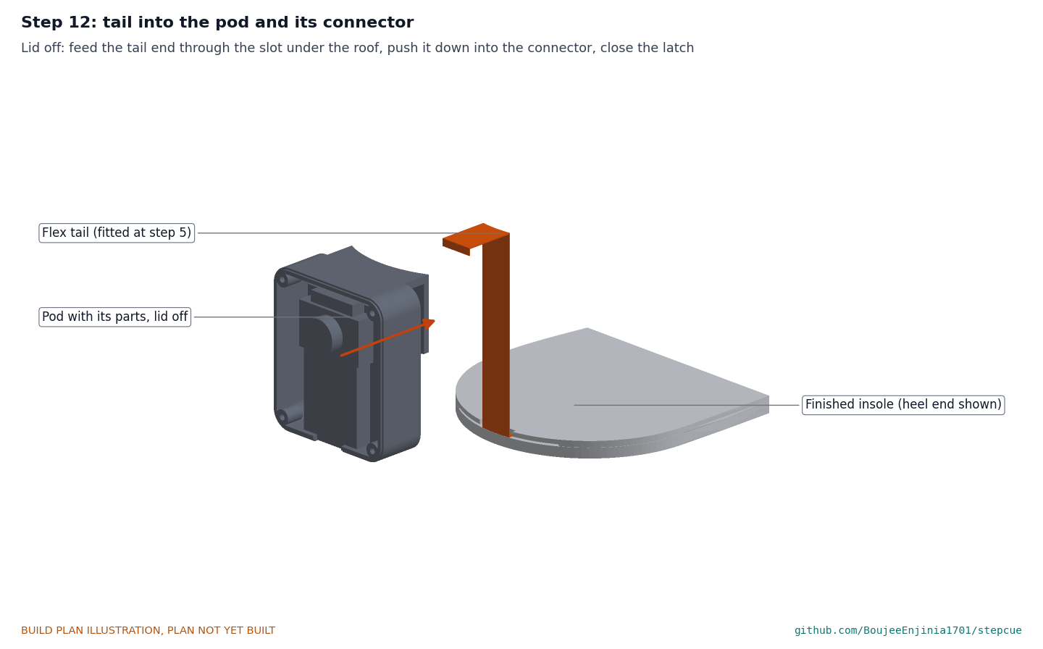
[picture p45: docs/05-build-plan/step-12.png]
Step 12


With the lid off, feed the tail's whole end through the slot under the roof from the shoe side, over the cell, and push it down into the connector, contacts toward the board. Close the latch. **Hold point:** the first checks of section 5 for the circuit and the sensors pass.

### Step 13: lid and four screws

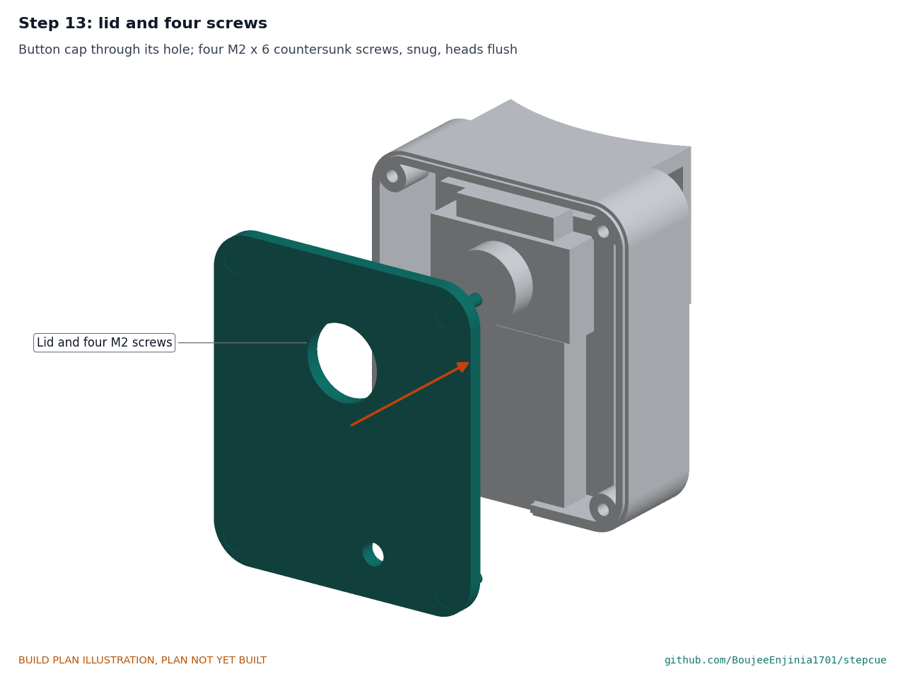
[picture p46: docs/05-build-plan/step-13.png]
Step 13


**Hold point:** safety stop S3, then plug the cell in. Lay the lid on with the button cap through its hole. Drive the four M2 x 6 screws until the heads are flush; do not overtighten.

### Step 14: into the shoe and over the heel counter

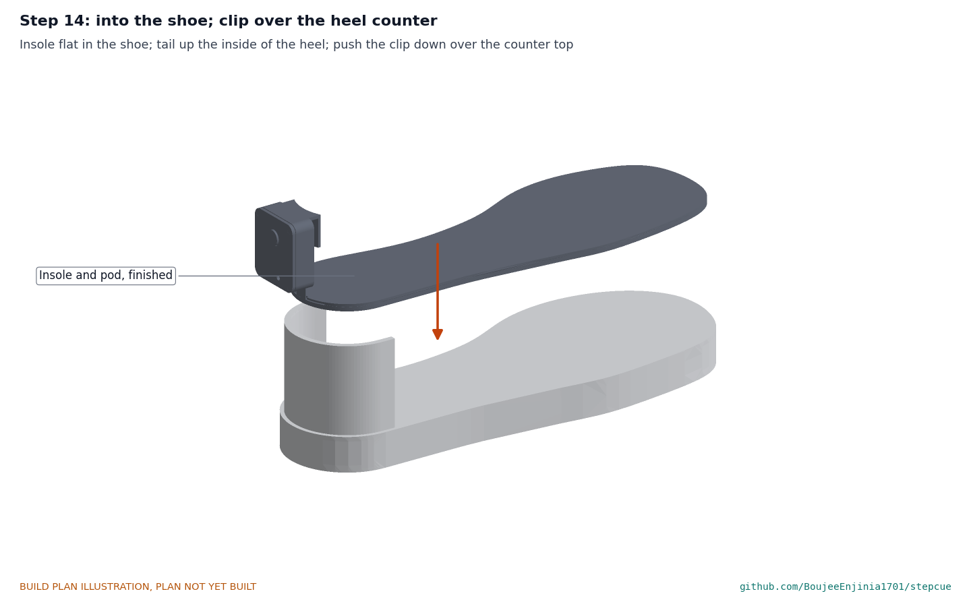
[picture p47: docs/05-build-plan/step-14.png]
Step 14


Lay the insole flat in the shoe, the tail running up the inside of the heel. Push the clip down over the counter's top until the bridge rests on it and the finger holds the tail flat against the counter. **Hold point:** safety stop S6.

## 5. First checks

These are the checks a TRL 4 test report would record; this plan only lists them. Requirement numbers are those of STC-REQ-001.

*Table 2. First checks.*

| Check | Requirement | How | Pass when |
| --- | --- | --- | --- |
| Insole thickness | R9 | Calipers at the heel and the ball of the foot | 4.3 to 4.7 mm; no bump above any sensor |
| Sensor response | R1 | With the supply on, press each sensor with a 1 kg mass on a 15 mm disc; read each analog input | Each reads clearly apart from unloaded; none reads from a neighbour's press |
| Sampling | R1, R2 | Log all six channels at rest for 10 s | 104 samples per second on every channel |
| Motor cue | R6, R7 | Trigger a test cue from the controller | Pulses of 100 ms at the set tempo, felt through the cover by hand |
| Pause button | R12 | Press the cap during a test cue | The cue stops |
| Pod mass and size | R10 | Weigh the closed pod; measure it | 35 g or less (26.8 g estimated); within 45 x 40 x 20 mm |
| Clip hold | R12 | Clip on and off one-handed on a shoe; pull straight up with a spring scale | On and off one-handed; it holds at least 2.5 N (about 6 N estimated) |
| Charging | R11, R12 | Charge from USB-C with the pod off the shoe, attended | Charges and stops; the cell stays below 40 °C |
| Current while running | R11 | Meter in the cell lead, detector running | About 1.5 mA (2.4 mA at most) |
| No exposed conductors | R15 | Look and feel along the insole edge and the tail | No copper or solder exposed |

## 6. Safety stops

Stop at each point. Carry on only when everything listed is true.

- **S1. Before soldering on the insole.** Fume extractor running; iron in its stand; contact adhesive and its can away from the bench.
- **S2. Before the cell comes into the workshop.** The cell is a protected type with a datasheet from its maker; its voltage is 3.6 to 4.1 V; it is not swollen, dented or warm. A charging spot is ready on a non-combustible surface (ceramic tile or steel tray).
- **S3. Before the cell is plugged in.** With the cell out, the module's battery pads and the interface board's supply read no short to ground; the polarity at the battery pads has been checked with a meter, not by wire colour; nothing in the pod can press on the cell.
- **S4. First charge.** Attended the whole time, pod off the shoe and lid off, on the charging spot; cell temperature checked every 15 minutes. Stop at once if the cell passes 40 °C or swells.
- **S5. Before the motor is driven from the module.** The diode is across the motor; a test cue starts at the lowest intensity.
- **S6. Before the insole is worn, even briefly.** Only by the builder, standing and seated, never walking with someone who freezes. Every edge of the clip finger is rounded; no copper, solder or sensor edge can be felt through the cover; the pod is closed with all four screws; every one of the eight traces reads continuous with a meter, from its connector way to its pad at the sensor or motor, before each wear, however short; the wearer's heel skin is checked after 10 minutes. StepCue is a research and educational prototype, not a medical device, and must not be relied on to prevent falls; wear trials belong to later, supervised work with ethics review.
- **S7. Never charge while worn or wet.** Take the insole and pod out of the shoe together to charge.

## 7. Tools, skills and workspace

**Tools.** Sharp craft knife with spare blades, steel rule and cutting mat; 11 mm hole punch; fine marker; small roller or spoon for burnishing; temperature-controlled soldering iron with a fine conical tip, thin solder and flux pen; fume extractor; tweezers; flush cutters and wire strippers for 30 AWG; multimeter; bench power supply with an adjustable current limit (0 to 5 V, 0 to 0.5 A); 3D printer that prints PETG with a bed of at least 60 x 60 mm; fine flat file; calipers; small Phillips or hex driver for M2; kitchen scale reading to 0.1 g; spring scale to 10 N.

**Skills.** No certified trade is needed. Careful knife work, fine through-hole and surface soldering on heat-sensitive film, basic 3D printing, safe use of a bench power supply and care with lithium cells. All circuits are extra-low voltage: 4.2 V at most at the cell, 5 V on USB.

**Workspace.** A bench about 1.0 x 0.6 m with good light and a magnifier; a ventilated place for the contact adhesive, away from the soldering; the charging spot of S2.

**Personal protective equipment.** Safety glasses when soldering and cutting; nitrile gloves for the adhesive.

## 8. Where the numbers come from

- Model and constructability checks: `cad/src/model.py` (`python cad/src/model.py --check`); STEP and STL exports in `cad/step/` and `cad/stl/`.
- Pictures: `cad/src/build_plan_media.py`, using `.kit/build_views.py`; written to `docs/05-build-plan/` and `cad/drawings/STC-DWG-101` to `STC-DWG-107`.
- General arrangement: `cad/drawings/STC-DWG-001.pdf`, Rev P4.
- Calculations: `docs/04-calcs/01-sizing.md` (STC-CAL-001 v0.4) and `docs/04-calcs/sizing.py`: insole stack (R9), pod size and mass (R10), clip (R12), power (R11), cost (R14).
- Bill of materials: `bom/bom.csv`.
- Decisions: `docs/decisions/0003-design-for-construction.md` (STC-DDR-003), with STC-DDR-001 and STC-DDR-002, indexed in `docs/06-design-decisions.md` (STC-DEC-001).
- Requirements: `docs/03-requirements.md` (STC-REQ-001 v0.6).

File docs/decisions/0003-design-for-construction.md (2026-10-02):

---
doc_id: STC-DDR-003
title: StepCue design for construction
project: StepCue
doc_type: Design decision record
version: "0.2"
status: Draft
date: '2026-10-02'
author: Amish Chadha
license: CERN-OHL-S-2.0
revisions:
- version: "0.1"
  date: '2026-10-01'
  author: Amish Chadha
  change: Changes that make the concept physically buildable, with the reason for each; made under Amish's 2026-09-30 instruction to make the design physically buildable; open for his review
- version: "0.2"
  date: '2026-10-02'
  author: Amish Chadha
  change: "Accepted by Amish, including the recommendations for A1 to A3"
---

# 0003: Design for construction

- **Date:** 2026-10-01
- **Status:** accepted. Amish, 2026-10-02: "i approve your recommendations for all 555 open decisions." This covers every change in Tables 1 and 2 and the recommendations in Table 3 (A1 to A3), which are now decided as recommended and recorded in the design decisions register (STC-DEC-001). A1 is decided for the supervised prototype sessions; an outside connector is to be decided before any take-home use. A3 adds a continuity check of every trace before each wear session.

## Context

On 2026-09-30 Amish asked for every repo to have an illustrated build plan showing how each component is made and how it fits the next, and wrote: "If you are realising that the design cannot be built as per concept, fix the design assumptions to match and be physically feasible as you draw the illustrations." The TRL 3 model of STC-DDR-002 showed what StepCue does (an insole with five sensors and a coin motor, a flex tail over the heel counter and a clip-on heel pod) but several of its parts could not be made, joined or fitted as drawn. Checking the model with build123d found two clashes (the flat clip finger and the flat tail cut 281 mm³ and 117 mm³ into the curved heel counter) and five parts held by nothing (cell, module, interface board, lid, and the tail end in the pod). Working through how each part is made found the rest.

The changes keep what StepCue does: the same five sensor sites, the same motor site and cue, the same controller, cell and interface circuit, the same 4.50 mm insole stack, the same clip over the heel counter and the same pod height and depth. Nothing here changes the pitch or the safety case. Every change is in `cad/src/model.py`, which now runs 471 constructability checks (`python cad/src/model.py --check`): nothing overlaps, every part touches what holds it, the gaps that must stay open do, every trace is clear of its neighbours, the sensor discs and the insole edge, and each pod part slides into the open tray without hitting what is already there. All 471 pass.

## Decision

*Table 1. Changes made to the model, the BOM and the calculations.*

| # | Problem in the concept | Change made | Why this way |
| --- | --- | --- | --- |
| P1 | The sensor laminate was one solid 0.8 mm sheet with pockets for the sensors. No such sheet can be bought or made, nothing filled the space round the 0.46 mm sensors, and there were no conductors from the sensors to the tail. | Two layers. A carrier of 125 µm polyimide film with 1.5 mm copper tape traces (0.3 mm with its adhesive), and a 0.5 mm closed-cell polyethylene foam spacer with a window round each sensor, the tail end, the motor leads and the crossover. The stack is unchanged at 0.8 mm (4.50 mm in all). | Copper tape on film is the simplest hand-made flexible circuit; polyimide takes solder where PET melts. The spacer fills the space round the sensors so the cover stays flat. |
| P2 | The sensors were plain discs with no tails or tabs, so they could not be connected. | Each sensor has its tail (7 mm wide, about 12 mm past the disc, short-tail type) with two tabs 2.54 mm apart, soldered to two tab pads on the carrier. Tails point to where the traces run: heel toward the toe, big-toe ball toward the centre line, the other three toward the heel. | The FSR 402 is joined by its tabs; pointing the tails lets eight traces reach every sensor with one crossover. |
| P3 | No trace routing: five sensors (each with a signal and the shared supply) and the motor need eight conductors on one face. | Eight traces at least 0.8 mm apart and 1.5 mm inside the insole edge, routed round the heel sensor and the motor. The supply runs down the centre line with branches to each sensor. One crossing is unavoidable (the outer midfoot sensor's supply branch over the little-toe-side ball trace); it crosses over an 8 x 8 mm polyimide tape patch. | Checked in 2D: no trace passes over a sensor disc; one insulated crossover is standard practice in copper tape circuits. |
| P4 | The 2.7 mm motor sat on a 0.2 mm EVA floor in a 2.3 mm blind pocket, and stood 0.4 mm into a relief cut in the underside of the laminate. Neither can be cut by hand in soft foam or a 0.8 mm film stack. | An 11 mm (10.6 mm) hole right through the EVA and the carrier, with a 4.4 mm lead notch. The motor's adhesive face sticks to the underside of the spacer; it stands 0.1 mm clear of the shoe's floor. Its leads come up through the notch to two pads beside the hole. | A punched through-hole is easy to make; the motor keeps 1.7 mm of foam over it, as before (0.5 spacer and 1.2 cover against 0.4 laminate and 1.2 cover), and the stack is unchanged. |
| P5 | The tail was drawn 12 mm wide and "bonded flush in the laminate" with no electrical joint. An 8-way, 1.0 mm pitch flat flex cable is 9 mm wide, and its 1.0 mm pitch is too fine to solder by hand onto copper tape. | Tail 9 mm wide. Its last 10 mm is slit into eight strips, fanned out and each soldered to a 2 x 5 mm pad; the pads are 4 mm apart, 10 to 15 mm from the back of the heel. | Slitting a flat flex cable into strips is a known hand technique; 4 mm pad spacing leaves room for a soldering iron. |
| P6 | The flat tail and the flat clip finger were drawn against a flat heel counter, but a moulded counter is curved (32 mm radius inside at the heel): the finger cut 281 mm³ into the counter and the tail 117 mm³. | The finger (1.5 mm) and the bridge are curved to the counter: the finger's outer face is 0.3 mm inside the counter's inner face, so it presses the tail against it. The tail bends to the same curve across its 9 mm width. The pod's flat shoe-side face touches the counter on the heel centre line and stands up to 5 mm off it at its edges. | The clip, not the pod body, holds the pod square; a curved finger grips evenly across its 26 mm width. A flat pod face keeps the pod 15 mm deep and its insides square. |
| P7 | The tail ended just inside the pod wall, at the top, with no connector, while the interface board it must reach was at the bottom behind the cell. The 9 mm tail cannot pass the 25 mm cell, which fills the shoe-side half of the pod. | An 8-way ZIF connector on a small adapter board (new BOM line 13) stands on the top edge of the interface board. The interface board moves to the top of the outer half of the pod and the controller module to the bottom. The tail enters through a 10 x 0.6 mm slot under the roof, crosses over the cell (3 mm clear) and drops 2 mm into the connector. | The shortest path for the tail, with no fold behind the cell. The ZIF holds a flat flex cable without solder, so the insole can be changed. |
| P8 | With the module at the bottom, its USB-C faces down instead of up, and the receptacle stopped 1.5 mm inside the wall, so a plug could not seat. | The receptacle stands 1.4 mm past the board end into a 9.4 mm notch in the bottom wall, its mouth 0.3 mm inside the outer face. The notch is open to the lid side so the module slides in, and the lid closes it. | A plug seats fully. Facing down, the port does not collect dirt or rain while the pod is on the shoe; charging is off the shoe in any case (R12). |
| P9 | The cell, module and interface board floated in the pod with no fixing. | The cell is held to the shoe-side wall by 0.3 mm double-sided transfer tape. The module and the interface board are held to the cell by 0.5 mm double-sided foam tape. These fill the gaps the concept left (0.3 and 0.5 mm). | No new parts in the pod; the lid then holds everything in place. |
| P10 | The lid had no fixing. | Four M2 x 6 countersunk thread-forming screws through the lid into four 4 mm bosses moulded in the tray corners. The pod is 37 mm wide (was 34) so the bosses clear the 25 mm cell as it slides in. | Screws are simple to print for and to undo for service. The pod stays within the 45 x 40 x 20 mm limit of R10. |
| P11 | The pause button was a 12 mm tact switch on the interface board, 0.5 mm short of the lid; nothing reached the 10 mm lid opening. | A 9.4 mm round cap on the switch stands 1 mm out of the lid, with 0.3 mm clearance in the opening. | The large button R12 asks for, reachable with the lid shut. |
| P12 | The cover and laminate covered the heel edge where the tail turns up the counter. | An 11 mm wide notch at the heel edge of the spacer and cover. | The tail turns up without being pinched. |

*Table 2. Knock-on changes.*

| Item | Change | Reason |
| --- | --- | --- |
| Mass | Pod base heavier (wider tray, bosses); connector, cap, screws and tapes added. Pod 27.2 g (was 25.2 g) against 35 g [R10]. | Parts added for construction. |
| Cost | BOM lines 3, 4, 6, 7, 10, 11 and 12 respecified, line 12 repriced (USD 5.00 to USD 6.00), lines 13 (tail connector, USD 2.50) and 14 (spacer foam, USD 3.00) added. Estimated cost USD 89.94 against the USD 200 value-engineering target (`budget_usd`), USD 110.06 under. | Parts added for construction. |
| Drawing | STC-DWG-001 Rev P3; making sketches STC-DWG-101 to 107 added. | Follows the model. |
| Documents | STC-CAL-001 v0.3, STC-REQ-001 v0.5, STC-PRC-001 v0.5: stack description, pod size and mass, cost and the tail updated. No requirement changed status. | Follows the model. |
| Insole stack | Unchanged at 4.50 mm (2.5 EVA, 0.3 carrier, 0.5 spacer, 1.2 cover); motor under 1.7 mm of foam. | |
| Clip | Unchanged in size: 1.5 mm finger 18 mm long, 26 mm wide, 1 mm interference, 7.5 N clamp [R12]. | |

*Table 3. Items that would change what StepCue does: proposed, then decided by Amish as recommended on 2026-10-02.*

| # | Question | Options | Recommendation |
| --- | --- | --- | --- |
| A1 | Daily charging. With the connector inside the pod, the insole and pod come out of the shoe together for charging (USB-C with the pod off the shoe, as R12 asks), and the insole cannot be left in the shoe. | (a) as modelled: insole and pod come out as one; (b) an outside connector so the pod unplugs from the tail; this adds a part and a wear point. | (a) for the prototype; revisit after the first user session at TRL 4. Decided by Amish, 2026-10-02: (a) for the supervised prototype sessions; decide on (b) before any take-home use. |
| A2 | The pod is 37 mm wide (was 34 mm), leaving 3 mm of the 40 mm R10 limit, to make room for the lid screws. | (a) accept 37 mm with screws; (b) keep 34 mm with a snap-fit lid and no screws. | (a): screws are easier to get right first time; a snap lid can follow once the pod is printed. Decided by Amish, 2026-10-02: (a). |
| A3 | The copper tape traces cross the arch and ball of the foot, where the insole flexes with every step, and may crack. | (a) build as modelled and inspect after the first wear trials at TRL 4; (b) lay the traces in a zigzag where they cross the ball of the foot. | (a): keep the first build simple; the flex life is a TRL 4 test. Decided by Amish, 2026-10-02: (a), with every trace checked for continuity before each wear session. |

## Consequences

- `design_state: constructable` in `project.yaml`. The build plan STC-BLD-001 shows every component and step in pictures generated from the model (`cad/src/build_plan_media.py`); open items are in the design decisions register STC-DEC-001.
- With A1 to A3 decided on 2026-10-02: insole and pod come out together for charging in supervised sessions, with an outside connector to be decided before take-home use; the pod is 37 mm wide with four M2 lid screws; the traces are built as modelled and checked for continuity before each wear session.
- Requirement status is unchanged: 11 met, none not met, 3 at risk (R3, R4, R5), 1 not verifiable at TRL 3 (R12) (STC-CAL-001 v0.3).
- The photoreal renders (`media/render-*.png`), `media/card.png`, `media/social-preview.png` and the appearance model `cad/src/product_model.py` still show the 34 mm pod with USB-C on top, the flat clip and the 12 mm tail; they need updating on Amish's Mac, where Blender is.
- The sensor tail length and tab spacing, and how far the module's USB-C receptacle stands past its board, are taken as typical values and are confirmed when the parts are bought (STC-DEC-001).

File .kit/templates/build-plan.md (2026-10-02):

---
doc_id: PRJ-BLD-001
title: Project prototype build plan
project: Project name
doc_type: Build plan
version: "0.1"
status: Draft
date: YYYY-MM-DD
author: Amish Chadha
license: CERN-OHL-S-2.0
revisions:
  - version: "0.1"
    date: YYYY-MM-DD
    author: Amish Chadha
    change: First build plan; design made constructable
---

# Project prototype build plan

**Plan, not yet built.** How to build the first proof-of-concept prototype, component by component. Building and testing to it is TRL 4 work. Decisions still to be made are kept in the design decisions register (`docs/06-design-decisions.md`), not here.

## 1. What you are building

Every component, pulled apart and numbered in build order

One short paragraph: what the prototype is, how many components, which are made and which are bought, and the main ways they are made.

## 2. What changed to make it buildable

| Component | The concept had | The buildable design has | Why |
| --- | --- | --- | --- |

## 3. Making the components

### 3.1 Component name

Making sketch

**What it is and what it is made from.**

**How to make it.**

1. Mark out ...
2. Cut ...

**How it fits the parts next to it.**

Close-up of the joint

**Check before moving on.**

## 4. Putting it together

### Step 1: ...

Step 1

## 5. First checks

| Check | Requirement | How | Pass when |
| --- | --- | --- | --- |

## 6. Safety stops

## 7. Tools, skills and workspace

## 8. Where the numbers come from

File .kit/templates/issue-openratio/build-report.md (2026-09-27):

---
name: Build report
about: Tell us what happened when you built, printed or tested part of this design
title: "Build report: "
labels: build-report
---

This is a research and educational prototype, not a medical device. It is a TRL 3 concept and is not released for fabrication. If you build any part of it, you do so at your own risk. Reports help everyone.

**What you built** (part, sub-assembly or test)

**Materials, tools and settings**

**What worked**

**What did not work, with photos or measurements if you have them**

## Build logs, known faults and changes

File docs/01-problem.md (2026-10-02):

---
doc_id: STC-PRB-001
title: StepCue problem statement
project: StepCue
doc_type: Problem statement
version: "0.4"
status: Draft
date: '2026-10-02'
author: Amish Chadha
license: CERN-OHL-S-2.0
revisions:
- version: "0.1"
  date: '2026-09-24'
  author: Amish Chadha
  change: Initial scaffold
- version: "0.2"
  date: '2026-09-25'
  author: Amish Chadha
  change: Populate to TRL 2 (problem, users, context, constraints, prior work with sources)
- version: "0.3"
  date: '2026-09-25'
  author: Amish Chadha
  change: One-insole question closed by Amish 2026-09-25 (STC-DDR-001); prevalence citation authors checked
- version: "0.4"
  date: '2026-10-02'
  author: Amish Chadha
  change: "First co-design partner as decided on 2026-10-02 (STC-DEC-001)"
---

# StepCue problem statement

Freezing of gait is a sudden, brief inability to step that affects a large share of people with Parkinson's disease and is a major cause of their falls. Cueing (a rhythm the person can step to) often helps them get moving again, but the wearable devices that deliver a cue at the right moment cost several hundred pounds or more, and none is open for others to build, audit or adapt.

## The problem

During a freeze the feet feel "glued to the floor" for a few seconds, most often when starting to walk, turning, passing through a doorway or approaching a target. A 2020 meta-analysis of 29 studies put the prevalence of freezing of gait at 39.9 % of people with Parkinson's disease, rising from about 22 % in the first five years after diagnosis to about 71 % after ten years ([Ge et al., Chinese Neurosurgical Journal, 2020](https://link.springer.com/article/10.1186/s41016-020-00197-y)). Freezing is triggered by specific situations, which the research literature has catalogued in detail ([Frontiers in Neurology systematic review, 2023](https://www.frontiersin.org/journals/neurology/articles/10.3389/fneur.2023.1326300/full)), and it responds only partly to medication.

External cues are one of the best-supported management strategies: a rhythmic sound, a vibration or a line on the floor gives the brain an external timing signal for the next step ([Ginis et al., narrative review of cueing for freezing of gait, 2018](https://www.sciencedirect.com/science/article/pii/S1877065717304049)). Cueing that runs all the time can become irritating and less effective, so research systems detect the onset of a freeze and cue only then. A review of wearable cueing devices reports closed-loop research systems with detection sensitivities of about 73 % to 97 % and detection delays of about 0.5 to 3.2 s, using accelerometers on the shank, trunk or ankles ([Sweeney et al., Sensors, 2019](https://www.mdpi.com/1424-8220/19/6/1277)). Plantar pressure alone has also been used to predict freezes: one study using insole pressure data identified about 94 to 95 % of episodes with about 77 to 80 % sensitivity and 83 to 85 % specificity at the window level, about 0.8 s before onset, and found one insole about as good as two ([Pardoel et al., Frontiers in Neurology, 2022](https://www.frontiersin.org/articles/10.3389/fneur.2022.831063/pdf); see also [Shalin et al., Journal of NeuroEngineering and Rehabilitation, 2021](https://jneuroengrehab.biomedcentral.com/articles/10.1186/s12984-021-00958-5)).

Commercial options exist but are costly. The Path Finder laser shoe attachment is listed at £834 ([Parkinson's UK Tech Guide](https://techguide.parkinsons.org.uk/catalogue/path-finder)). The CUE1+ chest-worn vibrotactile device is listed at £795 plus VAT, plus £60 a year for patches, and its sales were paused at the time of writing ([Parkinson's UK Tech Guide](https://techguide.parkinsons.org.uk/catalogue/cue1plus)). Neither is open hardware, and neither combines foot-pressure sensing with an on-demand cue at the foot.

The gap StepCue addresses: an open, low-cost, inspectable insole that senses how the foot is loading, recognizes the pattern of a freeze, and triggers a rhythmic cue only when it is needed, as a platform that researchers, clinics and patient groups can build and study.

## Users and context

| User | Need | Context |
| --- | --- | --- |
| Person with Parkinson's who freezes | A cue that arrives quickly when a freeze starts and stops once walking resumes; nothing that changes how the shoe feels | At home and outdoors, in their own shoes, several hours a day |
| Care partner | Fewer falls; a simple device that does not need daily fiddling | Home |
| Physiotherapist or clinician | Adjustable cue type and tempo; a record of how often cues fired | Clinic sessions and home programs |
| Researcher | An open reference design and data format for studying detection and cueing | University labs, gait studies |
| Open hardware community | A reproducible, buildable design | Makerspaces |

## Constraints

- Garage-buildable prototype, about $200 USD per unit of one instrumented insole and one heel pod (`budget_usd` in `project.yaml`), from off-the-shelf sensors and modules and 3D-printed parts.
- Fits in the wearer's own shoes: the insole must be no thicker than a normal replacement insole, and nothing rigid may sit under the heel or the metatarsal heads.
- Lithium cell and electronics stay outside the shoe, not under the foot.
- People with Parkinson's often have reduced hand dexterity: charging, fitting and switching must be possible with one hand and large features.
- Detection and cueing run on the device, with no phone or cloud needed for the core function; data stays with the wearer.
- Research and educational use only. StepCue is not a medical device and must not be relied on to prevent falls.

## Out of scope

- Diagnosis, disease staging or any clinical decision.
- Stimulation beyond a perceptible cue (no electrical stimulation).
- Cloud services and remote monitoring.
- Fall detection or emergency alerts.

## Open questions

- Which partner to co-design with first? Decided by Amish, 2026-10-02 (STC-DEC-001): a Parkinson's patient group, recruited through a local support group affiliated with the Parkinson's Foundation (the first candidate to approach), with a physiotherapy practice brought in for the first supervised user session.
- One insole or a pair for the first build: decided by Amish, 2026-09-25, one insole on the side the wearer reports freezing most (STC-DDR-001, D1).
- Where to obtain labeled plantar-pressure freeze data to develop the detector before any human testing, which in any case needs ethics approval and belongs to TRL 4 or later.

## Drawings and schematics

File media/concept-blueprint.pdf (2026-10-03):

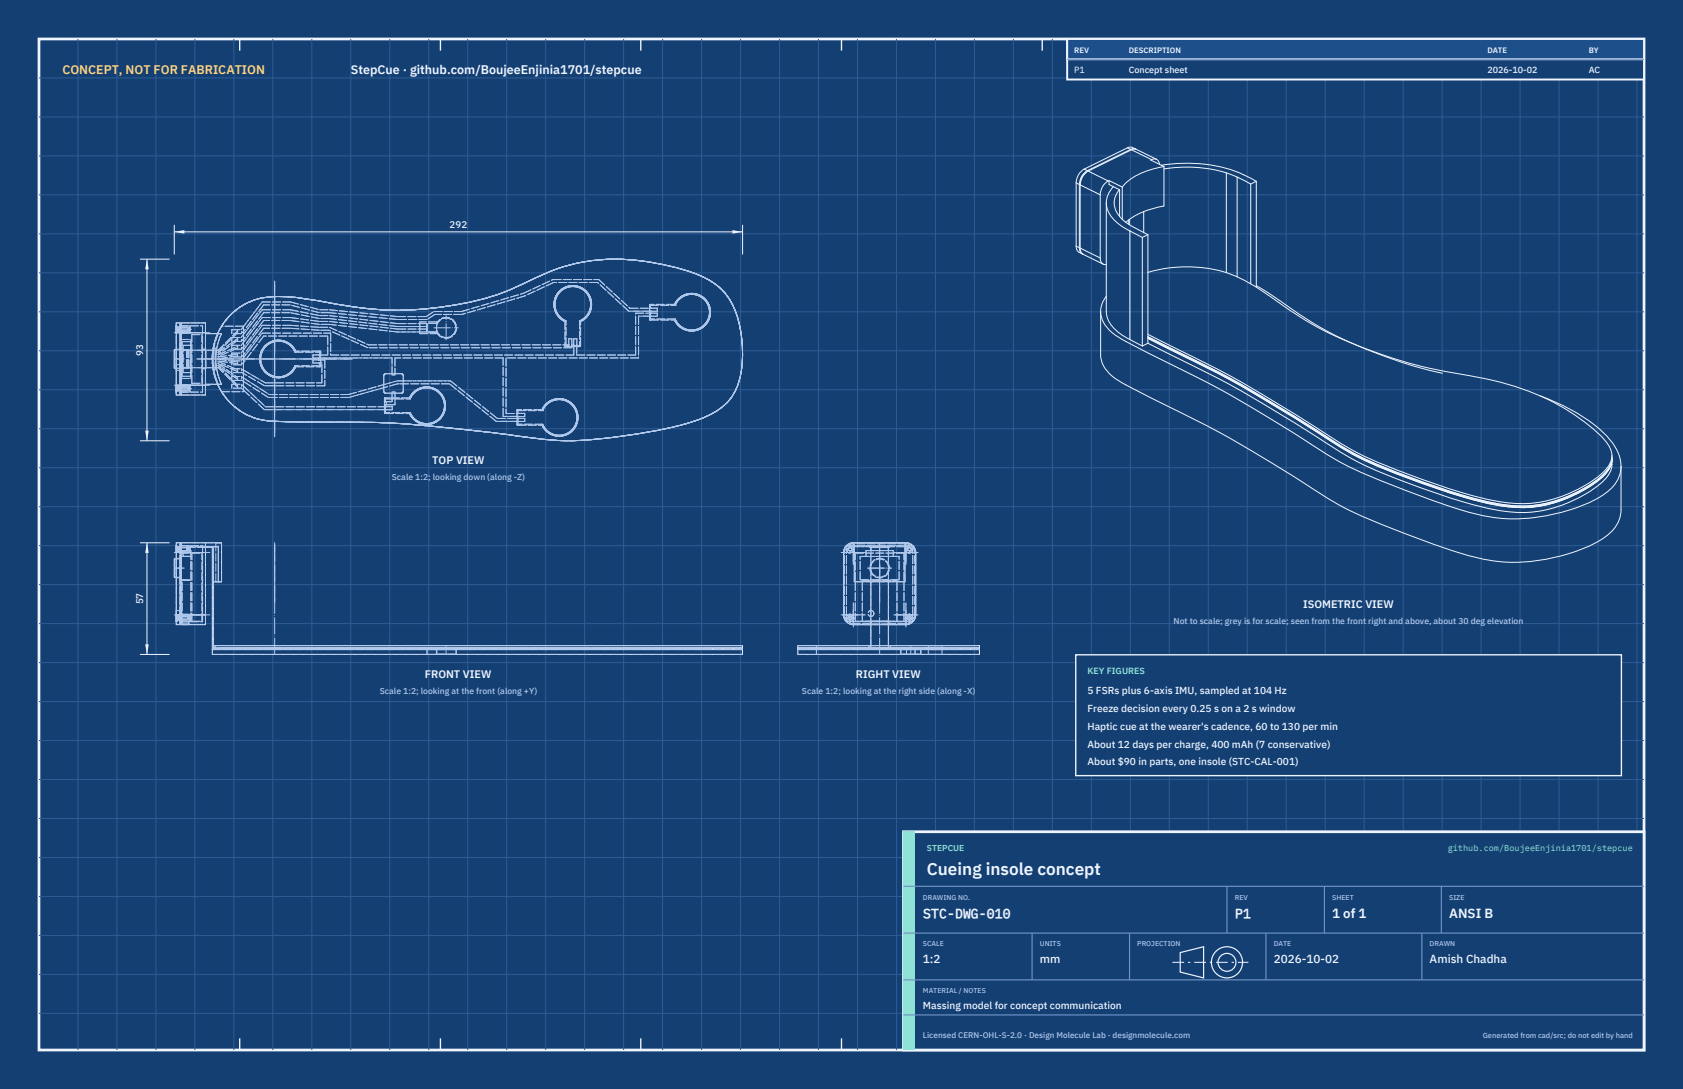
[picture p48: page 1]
CONCEPT, NOT FOR FABRICATION; StepCue · github.com/BoujeeEnjinia1701/stepcue; FRONT VIEW; TOP VIEW; RIGHT VIEW; ISOMETRIC VIEW; REV; DESCRIPTION; DATE; Concept sheet; STEPCUE; github.com/BoujeeEnjinia1701/stepcue; DRAWING NO. STC-DWG-010; REV P1; SHEET 1 of 1; SIZE ANSI B; SCALE 1:2; UNITS mm; PROJECTION; DRAWN Amish Chadha; Licensed CERN-OHL-S-2.0 · Design Molecule Lab · designmolecule.com; Generated from cad/src; do not edit by hand

Scale 1:2; looking down (along -Z)

Not to scale; grey is for scale; seen from the front right and above, about 30 deg elevation

KEY FIGURES
5 FSRs plus 6-axis IMU, sampled at 104 Hz
Freeze decision every 0.25 s on a 2 s window
Haptic cue at the wearer's cadence, 60 to 130 per min
About 12 days per charge, 400 mAh (7 conservative)
About $90 in parts, one insole (STC-CAL-001)

Scale 1:2; looking at the front (along +Y)

Scale 1:2; looking at the right side (along -X)

Cueing insole concept

MATERIAL / NOTES
Massing model for concept communication

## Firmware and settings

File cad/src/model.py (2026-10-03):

"""StepCue parametric model (build123d), TRL 3, constructable design (STC-DDR-003).

Run from the repo root:
    python cad/src/model.py            export STEP and STL into cad/step and cad/stl
    python cad/src/model.py --check    run the constructability checks and print the results

Coordinates (mm): X runs heel (0) to toe, Y points to the medial (big-toe) side of a
right insole, Z is up with the underside of the insole at Z = 0. The shoe heel counter
is a curved wall round the heel: its inner face follows the insole's heel cup (radius 32
about the point X = 32, Y = 0) and it is counter_t thick, so behind the heel centre its
inner face is at X = 0 and its outer face at X = -counter_t. Its top edge is at Z = counter_h.
The heel pod hangs on the outside of the counter and clips over its top edge.

Decisions reflected: STC-DDR-001 and STC-DDR-002 (2026-09-25), and the design for
construction changes of STC-DDR-003 (2026-10-01, accepted by Amish on 2026-10-02):
two-layer sensor laminate (carrier film with copper tape traces, foam spacer with
windows), sensor tails and tab pads, routed traces with one insulated crossover, motor
in a through-hole bonded under the spacer, 8-way 9 mm tail slit and fanned onto pads,
tail connector on the interface board, interface board above the module, USB-C through
the bottom wall, curved clip finger, taped internal parts, lid on four M2 screws into
corner bosses, button cap through the lid. Model revision of 2026-10-02 (Amish's decisions):
smooth spline insole outline, pod corners rounded to 5 mm with a parting-line groove.
BUILD PLAN MODEL, PLAN NOT YET BUILT.
"""
from pathlib import Path
import itertools
import math
import sys

import numpy as np

# Top-level parameters (mm). Edit these, not the geometry below.
PARAMS = {
    # Insole, about EU 42 (US men's 8.5)
    "insole_l": 272.0,        # heel to toe
    "foam_t": 2.5,            # EVA base (2.5 mm by decision O3, STC-DDR-002)
    "film_t": 0.25,           # carrier: 125 um polyimide film plus transfer adhesive
    "trace_t": 0.05,          # copper tape traces on the carrier
    "spacer_t": 0.5,          # closed-cell polyethylene foam spacer with windows
    "cover_t": 1.2,           # PU foam top cover
    "trace_w": 1.5,           # copper tape trace width
    # Force-sensing resistors (Interlink FSR 402: 18.3 dia, 14.68 active, 0.46 thick)
    "fsr_d": 18.3,
    "fsr_active_d": 14.68,
    "fsr_t": 0.46,
    "fsr_tail": (7.0, 12.0),  # tail width, length beyond the disc (short-tail type; confirm on the part)
    "tab_in": 2.0,            # tab centres this far in from the tail end
    "tab_pitch": 2.54,
    # Sensor sites (x, y): heel, lateral midfoot, first MTH, fifth MTH, hallux; tail directions
    "fsr_xy": ((34, 0), (110, -24), (185, 28), (178, -30), (246, 24)),
    "fsr_dir": ((1, 0), (-1, 0), (0, -1), (-1, 0), (-1, 0)),
    # Coin ERM motor under the medial arch (Precision Microdrives 310-103 class, 10 x 2.7)
    "motor_d": 10.0,
    "motor_t": 2.7,
    "motor_xy": (120.0, 16.0),
    "pocket_clear": 0.3,      # radial clearance of the motor hole
    # Flat flex tail: 8-way, 1.0 mm pitch (9 mm wide as bought)
    "tail_w": 9.0,
    "tail_t": 0.3,
    "tail_n": 8,
    "slit_x": (3.0, 13.0),    # the tail end is slit into eight strips between these X
    "pad_x": (10.0, 15.0),    # tail pads on the carrier
    "pad_pitch": 4.0,
    # Shoe heel counter (context and clip interface)
    "heel_r": 32.0,           # heel cup radius of the insole outline
    "counter_t": 3.5,
    "counter_h": 55.0,
    # Heel pod body (outside the counter)
    "pod_x": 15.0,            # depth away from the shoe, including the lid
    "pod_y": 37.0,            # width across the heel (34 in the concept; widened for the lid bosses)
    "pod_z": 42.0,            # height
    "wall": 1.5,
    "lid_t": 2.0,
    "pod_r": 5.0,             # corner radius of the pod body seen from the lid (2026-10-02 decision)
    "groove": 0.5,            # parting-line groove round the base rim at the lid: width and depth
    # Clip over the counter top
    "bridge_t": 2.0,
    "bridge_w": 26.0,
    "finger_t": 1.5,
    "finger_l": 18.0,
    "clip_interference": 1.0,
    # Internal parts (envelopes) and how they are held
    "cell": (5.2, 25.0, 35.0),        # 400 mAh LiPo, 502535 class: X (thick), Y, Z
    "cell_tape": 0.3,                 # double-sided transfer tape, cell to the shoe-side wall
    "foam_tape": 0.5,                 # double-sided foam tape, module and interface board to the cell
    "module": (4.5, 17.8, 21.0),      # XIAO nRF52840 Sense class: X (with parts), Y, Z (USB-C down)
    "usb_rec": (3.2, 8.94, 1.4),      # USB-C receptacle: X, Y, and how far it stands past the board end
    "usb_open": (9.4, 0.2),           # opening in the bottom wall: width, clearance round the receptacle
    "iface": (5.0, 20.0, 12.0),       # interface perfboard with MOSFETs, resistors and tact switch
    "zif": (4.0, 14.0, 3.0),          # 8-way ZIF connector on its adapter board, on top of the interface board
    "cap_d": 9.4,                     # pause button cap
    "cap_proud": 1.0,                 # cap stands this far out of the lid
    "button_d": 10.0,                 # pause button opening in the lid
    "led_d": 3.0,                     # status LED window in the lid
    "led_up": 4.0,                    # LED window height above the module's lower end
    "boss_d": 4.0,                    # lid screw bosses in the tray corners
    "boss_l": 5.0,
    "pilot_d": 1.6,                   # M2 thread-forming pilot
    "screw_l": 6.0,                   # M2 x 6 countersunk thread-forming screws
    "csk_d": 3.8,
    # Crossover of the lateral midfoot common branch over the fifth MTH signal trace
    "patch": 8.0,
}


def concept_outline(p, grow=0.0, n=40):
    """The TRL 3 insole outline as a polyline (x, y): straight runs between set half-widths, an
    elliptical toe cap and a circular heel cup (radius heel_r about X = heel_r). It has corners
    where the straight runs meet; outline_points() smooths it."""
    k = p["insole_l"] / 272.0
    xs = np.linspace(32, 255, n) * k
    lat = np.interp(xs, np.array([32, 100, 180, 230, 255]) * k, [32, 33, 42, 38, 28]) + grow
    med = np.interp(xs, np.array([32, 100, 140, 190, 230, 255]) * k, [32, 24, 30, 52, 50, 38]) + grow
    pts = [(x, -w) for x, w in zip(xs, lat)]
    for t in np.linspace(-np.pi / 2, np.pi / 2, 24)[1:-1]:          # toe cap
        pts.append((255 * k + (17 + grow) * np.cos(t), 5 + (33 + grow) * np.sin(t)))
    pts += [(x, w) for x, w in zip(xs[::-1], med[::-1])]
    for t in np.linspace(np.pi / 2, 3 * np.pi / 2, 24)[1:-1]:       # heel cup
        pts.append((32 * k + (32 + grow) * np.cos(t), (32 + grow) * np.sin(t)))
    return pts


def outline_points(p, grow=0.0, step=30.0):
    """Control points of the smooth insole outline (decision of 2026-10-02): the concept outline
    from the lateral heel round the toe to the medial heel, resampled every `step` mm so its
    corners are not copied into the spline, plus the heel cup arc kept exact (the clip and the
    tail fit the heel counter there)."""
    from shapely.geometry import LineString
    n = 40
    k = p["insole_l"] / 272.0
    front = concept_outline(p, grow, n)[: 2 * n + 22]                  # lateral side, toe cap, medial side
    line = LineString(front)
    m = int(round(line.length / step))
    pts = [(q.x, q.y) for q in (line.interpolate(i * line.length / m) for i in range(m + 1))]
    r = p["heel_r"] + grow
    pts += [(32 * k + r * math.cos(t), r * math.sin(t)) for t in np.linspace(np.pi / 2, 3 * np.pi / 2, 13)[1:-1]]
    return pts


_OUTLINE_CACHE = {}


def outline_edge(p, grow=0.0):
    """The insole outline as one smooth closed spline (decision of 2026-10-02: smooth spline
    outline, traces kept 1.5 mm inside it). Replaces the TRL 3 polyline outline."""
    from build123d import Edge, Vector
    return Edge.make_spline([Vector(x, y, 0) for x, y in outline_points(p, grow)], periodic=True)


def outline(p, grow=0.0, n=720):
    """The smooth spline outline sampled as n points (x, y) about 0.9 mm apart, for layout checks and drawings."""
    key = (p["insole_l"], round(grow, 4), n)
    if key not in _OUTLINE_CACHE:
        e = outline_edge(p, grow)
        _OUTLINE_CACHE[key] = [(v.X, v.Y) for v in (e.position_at(i / n) for i in range(n))]
    return list(_OUTLINE_CACHE[key])


def derived(params=None):
    p = dict(params or PARAMS)
    p["lam_t"] = p["film_t"] + p["trace_t"] + p["spacer_t"]          # 0.8 mm, as in the concept
    p["stack"] = p["foam_t"] + p["lam_t"] + p["cover_t"]
    p["z_film"] = p["foam_t"]
    p["z_trace"] = p["foam_t"] + p["film_t"]
    p["z_spacer"] = p["z_trace"] + p["trace_t"]
    p["z_cover"] = p["z_spacer"] + p["spacer_t"]
    p["motor_gap"] = p["z_spacer"] - p["motor_t"]                     # air under the motor (0.1)
    # kept for cad/src/product_model.py (appearance model)
    p["pocket_floor"] = p["motor_gap"]
    p["motor_relief"] = p["film_t"] + p["trace_t"]
    p["tail_top"] = p["counter_h"] + p["tail_t"]
    p["pod_top"] = p["tail_top"] + p["bridge_t"]
    p["pod_bot"] = p["pod_top"] - p["pod_z"]
    p["pod_x1"] = -p["counter_t"]                                     # shoe-side face of the pod
    p["pod_x0"] = p["pod_x1"] - p["pod_x"]                            # outer face of the lid
    p["finger_x0"] = p["tail_t"]                                      # at the heel centre
    p["clip_gap_fitted"] = p["counter_t"] + p["tail_t"]
    p["clip_gap_free"] = p["clip_gap_fitted"] - p["clip_interference"]
    p["cav_x"] = p["pod_x"] - p["wall"] - p["lid_t"]
    p["cav_y"] = p["pod_y"] - 2 * p["wall"]
    p["cav_z"] = p["pod_z"] - 2 * p["wall"]
    p["r_in"] = p["heel_r"]                                           # counter inner face
    p["r_out"] = p["heel_r"] + p["counter_t"]                         # counter outer face
    p["r_tail"] = p["heel_r"] - p["tail_t"]
    p["r_finger"] = p["r_tail"] - p["finger_t"]
    # pod interior, from the shoe-side wall outward and from the floor up
    x1, w = p["pod_x1"], p["wall"]
    p["x_wall_in"] = x1 - w
    p["x_cell"] = (p["x_wall_in"] - p["cell_tape"] - p["cell"][0], p["x_wall_in"] - p["cell_tape"])
    p["x_outer"] = p["x_cell"][0] - p["foam_tape"]                    # shoe-side face of module and board
    p["z_floor"] = p["pod_bot"] + w
    p["z_roof"] = p["pod_top"] - w
    p["z_cell"] = (p["z_floor"] + 0.2, p["z_floor"] + 0.2 + p["cell"][2])
    p["z_module"] = (p["z_floor"] + 0.2, p["z_floor"] + 0.2 + p["module"][2])
    p["z_iface"] = (p["z_module"][1] + 0.3, p["z_module"][1] + 0.3 + p["iface"][2])
    p["z_zif"] = (p["z_iface"][1], p["z_iface"][1] + p["zif"][2])
    p["z_button"] = sum(p["z_iface"]) / 2
    p["z_led"] = p["z_module"][0] + p["led_up"]
    p["x_lid_in"] = p["pod_x0"] + p["lid_t"]
    p["x_drop"] = p["x_outer"] - p["zif"][0] / 2                       # where the tail drops into the connector
    # centres, kept for cad/src/product_model.py
    p["cell_c"] = (sum(p["x_cell"]) / 2, 0, sum(p["z_cell"]) / 2)
    p["module_c"] = (p["x_outer"] - p["module"][0] / 2, 0, sum(p["z_module"]) / 2)
    p["iface_c"] = (p["x_outer"] - p["iface"][0] / 2, 0, sum(p["z_iface"]) / 2)
    by = p["cav_y"] / 2 - p["boss_d"] / 2 + 0.2                     # bosses run into the side and end walls
    p["bosses"] = [(s * by, z) for s in (-1, 1)
                   for z in (p["z_floor"] + p["boss_d"] / 2 - 0.2, p["z_roof"] - p["boss_d"] / 2 + 0.2)]
    return p


# ----------------------------------------------------------------- 2D layout of the insole circuit
def fsr_tabs(p):
    """For each sensor: (centre, tail direction, tab on the lateral side (or heel side for a tail
    pointing across the foot), the other tab)."""
    out = []
    for (x, y), (dx, dy) in zip(p["fsr_xy"], p["fsr_dir"]):
        r = p["fsr_d"] / 2 + p["fsr_tail"][1] - p["tab_in"]
        cx, cy = x + dx * r, y + dy * r
        nx, ny = -dy, dx                       # perpendicular
        h = p["tab_pitch"] / 2
        a, b = (cx - nx * h, cy - ny * h), (cx + nx * h, cy + ny * h)
        a, b = sorted((a, b), key=lambda t: (t[1], t[0]) if dx else (t[0], t[1]))   # lateral or heel side first
        out.append(((x, y), (dx, dy), a, b))
    return out


def pad_y(p, i):
    return (i - (p["tail_n"] - 1) / 2) * p["pad_pitch"]


def trace_paths(p=None):
    """The copper tape traces as named polylines (x, y). Signal pads from lateral to medial:
    0 lateral midfoot, 1 fifth MTH, 2 heel, 3 common supply, 4 first MTH, 5 motor -, 6 motor +, 7 hallux.
    The common branch to the lateral midfoot sensor crosses the fifth MTH trace over an
    insulating patch: its raised part is 'bridge' in trace_layout()."""
    p = derived(p)
    T = fsr_tabs(p)
    heel, mid, mth1, mth5, hal = T
    x0 = p["pad_x"][1]
    Y = [pad_y(p, i) for i in range(8)]
    mx, my = p["motor_xy"]
    mlx = mx - p["motor_d"] / 2 - p["pocket_clear"] - 4.7               # motor lead pads end here
    mp = (my - 1.4, my + 1.4)
    pc = crossing(p)
    hp = p["patch"] / 2 + 0.4
    return {
        "Lateral midfoot signal": [(x0, Y[0]), (27, mid[2][1]), mid[2]],
        "Fifth MTH signal": [(x0, Y[1]), (29, -19), (70, -19), (95, -12), (122, -12), (146, mth5[2][1]), mth5[2]],
        "Heel signal": [(x0, Y[2]), (27, -13), (57, -13), (57, heel[2][1]), heel[2]],
        "Common supply": [(x0, Y[3]), (26, 12.5), (60, 12.5), (60, heel[3][1]), heel[3]],
        "Common spine": [(60, heel[3][1]), (218, heel[3][1]), (218, hal[2][1]), hal[2]],
        "Common to lateral midfoot (heel side)": [(pc[0], heel[3][1]), (pc[0], pc[1] + hp)],
        "Common to lateral midfoot (sensor side)": [(pc[0], pc[1] - hp), (pc[0], mid[3][1]), mid[3]],
        "Common to fifth MTH": [(150, heel[3][1]), (150, mth5[3][1]), mth5[3]],
        "Common to first MTH": [(mth1[3][0], heel[3][1]), mth1[3]],
        "First MTH signal": [(x0, Y[4]), (26, 16.5), (40, 16.5), (55, 15.5), (60, 15.5), (80, 6.5),
                             (mth1[2][0], 6.5), mth1[2]],
        "Motor -": [(x0, Y[5]), (26, 20.5), (40, 20.5), (55, 18.5), (60, 18.5), (95, mp[0]), (mlx, mp[0])],
        "Motor +": [(x0, Y[6]), (26, 24.5), (40, 24.5), (55, 21.5), (60, 21.5), (95, mp[1]), (mlx, mp[1])],
        "Hallux signal": [(x0, Y[7]), (26, 28.5), (40, 28.5), (55, 24.5), (60, 24.5), (95, 21), (110, 21),
                          (114, 23.6), (128, 23.6), (160, 33), (175, 40), (198, 40), (214, hal[3][1]), hal[3]],
    }


NET = {"Common supply": "C", "Common spine": "C", "Common to lateral midfoot (heel side)": "C",
       "Common to lateral midfoot (sensor side)": "C", "Common to fifth MTH": "C", "Common to first MTH": "C"}


def crossing(p):
    """Where the common branch to the lateral midfoot sensor crosses the fifth MTH trace."""
    x = 93.0
    y = -19 + (x - 70) / (95 - 70) * 7
    return (x, y)


def trace_layout(p=None):
    """Shapely polygons: {'traces': per-path polygons, 'pads': tail pads, 'tabs': tab pads,
    'motor_pads', 'patch', 'bridge'}."""
    from shapely.geometry import LineString, box
    p = derived(p)
    w = p["trace_w"]
    paths = trace_paths(p)
    polys = {k: LineString(v).buffer(w / 2, cap_style=2, join_style=2) for k, v in paths.items()}
    pads = [box(p["pad_x"][0], pad_y(p, i) - 1.0, p["pad_x"][1], pad_y(p, i) + 1.0) for i in range(8)]
    tabs = []
    for c, (dx, dy), a, b in fsr_tabs(p):
        for t in (a, b):
            lx, ly = (1.6, 3.0) if dx else (3.0, 1.6)
            lx, ly = (3.0, 1.6) if dx else (1.6, 3.0)
            tabs.append(box(t[0] - lx / 2, t[1] - ly / 2, t[0] + lx / 2, t[1] + ly / 2))
    mx, my = p["motor_xy"]
    mlx = mx - p["motor_d"] / 2 - p["pocket_clear"] - 4.7
    motor_pads = [box(mlx - 3.0, y - 0.75, mlx, y + 0.75) for y in (my - 1.4, my + 1.4)]
    pc = crossing(p)
    h = p["patch"] / 2
    patch = box(pc[0] - h, pc[1] - h, pc[0] + h, pc[1] + h)
    hp = h + 0.4
    bridge = box(pc[0] - w / 2, pc[1] - hp, pc[0] + w / 2, pc[1] + hp)
    return {"traces": polys, "pads": pads, "tabs": tabs, "motor_pads": motor_pads, "patch": patch, "bridge": bridge}


def fsr_shapes2d(p=None, grow=0.0):
    from shapely.geometry import Point, box
    from shapely import affinity
    p = derived(p)
    out = []
    r = p["fsr_d"] / 2
    tw, tl = p["fsr_tail"]
    for (x, y), (dx, dy) in zip(p["fsr_xy"], p["fsr_dir"]):
        disc = Point(x, y).buffer(r + grow, 64)
        tail = box(r - 2, -tw / 2 - grow, r + tl + grow, tw / 2 + grow)
        tail = affinity.rotate(tail, math.degrees(math.atan2(dy, dx)), origin=(0, 0))
        tail = affinity.translate(tail, x, y)
        out.append(disc.union(tail))
    return out


def strips2d(p=None):
    """The slit end of the flex tail: eight strips fanned from the tail onto the pads."""
    from shapely.geometry import Polygon
    p = derived(p)
    xa, xb = p["slit_x"]
    out = []
    for i in range(p["tail_n"]):
        ya = (i - (p["tail_n"] - 1) / 2) * p["tail_w"] / p["tail_n"]
        yb = pad_y(p, i)
        h = 0.45
        out.append(Polygon([(xa, ya - h), (xb, yb - h), (xb, yb + h), (xa, ya + h)]))
    return out


# ----------------------------------------------------------------- solids
def _face(poly):
    from build123d import Face, Wire, Vector
    pts = list(poly.exterior.coords)[:-1]
    return Face(Wire.make_polygon([Vector(x, y, 0) for x, y in pts], close=True))


def _prism(poly, z0, t):
    from build123d import Pos, extrude
    from shapely.geometry import MultiPolygon
    geoms = poly.geoms if isinstance(poly, MultiPolygon) else [poly]
    out = None
    for g in geoms:
        s = Pos(0, 0, z0) * extrude(_face(g), amount=t, dir=(0, 0, 1))
        out = s if out is None else out + s
    return out


def _slab(p, z0, t, grow=0.0):
    """Insole layer: the smooth spline outline extruded from z0 by t."""
    from build123d import Face, Pos, Wire, extrude
    return Pos(0, 0, z0) * extrude(Face(Wire([outline_edge(p, grow)])), amount=t, dir=(0, 0, 1))


def _zcyl(r, z0, h, x=0.0, y=0.0):
    from build123d import Cylinder, Pos
    return Pos(x, y, z0 + h / 2) * Cylinder(r, h)


def _xcyl(r, x0, x1, y, z):
    from build123d import Cylinder, Pos, Rot
    return Pos((x0 + x1) / 2, y, z) * Rot(0, 90, 0) * Cylinder(r, abs(x1 - x0))


def _box(x0, x1, y0, y1, z0, z1):
    from build123d import Box, Pos
    return Pos((x0 + x1) / 2, (y0 + y1) / 2, (z0 + z1) / 2) * Box(abs(x1 - x0), abs(y1 - y0), abs(z1 - z0))


def _rbox(x0, x1, hy, z0, z1, r):
    """Box along X from x0 to x1, Y from -hy to hy, Z from z0 to z1, with its four edges
    parallel to X rounded to radius r (r = 0 leaves them square)."""
    from build123d import Axis, fillet
    b = _box(x0, x1, -hy, hy, z0, z1)
    return fillet(b.edges().filter_by(Axis.X), r) if r > 0 else b


def _ring(r0, r1, z0, h, p):
    """Part of an annulus round the heel cup centre, near the heel (X < 10)."""
    c = p["heel_r"] * p["insole_l"] / 272.0
    return (_zcyl(r1, z0, h, c, 0) - _zcyl(r0, z0 - 0.1, h + 0.2, c, 0))
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

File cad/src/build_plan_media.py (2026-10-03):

"""StepCue prototype build plan pictures (STC-BLD-001, STANDARDS section 18).

Run from the repo root:
    python cad/src/build_plan_media.py [overview|sheets|layouts|joints|steps|wiring] [item ...]
With no argument it draws everything; with a group and item numbers it draws only those
(for example `sheets 105` or `joints 05 06`), so pictures can be made one process at a time.
Every 3D picture is drawn from cad/src/model.py (build_parts), so the pictures and the model
never disagree:
    docs/05-build-plan/overview.png        every component pulled apart, numbered in build order
    cad/drawings/STC-DWG-101 to 107        making sketches for the made components
    docs/05-build-plan/insole-layout.png   the circuit on the carrier film, full-size figures
    docs/05-build-plan/joint-NN.png        close-ups of the joints that need explaining
    docs/05-build-plan/step-NN.png         one picture per assembly step
    docs/05-build-plan/wiring.png          block-level wiring (matplotlib)
Uses .kit/build_views.py. BUILD PLAN ILLUSTRATION, PLAN NOT YET BUILT.
"""
import shutil
import sys
from pathlib import Path

ROOT = Path(__file__).resolve().parents[2]
sys.path[:0] = [str(ROOT / ".kit"), str(ROOT / "cad" / "src")]
import build_views as bv  # noqa: E402
from build_views import Part  # noqa: E402
import model as M  # noqa: E402

OUT = ROOT / "docs" / "05-build-plan"
DWG = ROOT / "cad" / "drawings"
DATE = "2026-10-01"
P1 = ("P1", "Making sketch for the prototype build plan", DATE, "AC")
OUTLINE_P2 = dict(rev="P2", history=(P1, ("P2", "Smooth spline insole outline", "2026-10-02", "AC")))
POD_P2 = dict(rev="P2", history=(P1, ("P2", "5 mm pod corners, parting-line groove", "2026-10-02", "AC")))
REPO = "github.com/BoujeeEnjinia1701/stepcue"
_C = {}


def C():
    if not _C:
        _C.update(M.build_parts())
        _C["shoe"] = M.shoe_context()
    return _C


def P():
    return C()["_p"]


COL = {"foam": "#374151", "film": "#D97706", "traces": "#9A3412", "patch": "#FCD34D", "fsrs": "#0F766E",
       "tail": "#EA580C", "motor": "#64748B", "spacer": "#7DD3FC", "cover": "#8CC7C0", "base": "#6B7280",
       "cell": "#B91C1C", "tape": "#FDE68A", "module": "#1D4ED8", "iface": "#16A34A", "zif": "#7C3AED",
       "cap": "#0F766E", "lid": "#D1D5DB", "screws": "#111827", "shoe": "#C8CDD3"}


def fuse(*keys):
    out = None
    for k in keys:
        s = C()[k]
        out = s if out is None else out + s
    return out


def part(name, shape, color, explode=(0, 0, 0), alpha=1.0):
    return Part(name, shape, color, None, tuple(explode), alpha)


def mv(p, e):
    return Part(p.name, p.shape, p.color, None, tuple(e), p.alpha)


def made():
    """The components in build order."""
    return {
        "foam": part("EVA base", C()["foam"], COL["foam"]),
        "film": part("Carrier film", C()["film"], COL["film"]),
        "traces": part("Copper traces and crossover patch", fuse("traces", "patch", "bridge"), COL["traces"]),
        "fsrs": part("Pressure sensors (5)", C()["fsrs"], COL["fsrs"]),
        "tail": part("Flex tail", C()["tail"], COL["tail"]),
        "motor": part("Vibration motor and leads", fuse("motor", "leads"), COL["motor"]),
        "spacer": part("Spacer foam", C()["spacer"], COL["spacer"]),
        "cover": part("Top cover", C()["cover"], COL["cover"]),
        "base": part("Pod base with clip", C()["base"], COL["base"]),
        "cell": part("Cell and its tape", fuse("cell", "cell_tape"), COL["cell"]),
        "module": part("Controller module and its tape", fuse("module", "module_tape"), COL["module"]),
        "iface": part("Interface board, connector, button cap", fuse("iface", "iface_tape", "zif", "cap"), COL["iface"]),
        "lid": part("Lid and four M2 screws", fuse("lid", "screws"), COL["lid"]),
    }


INSOLE = ("foam", "film", "traces", "fsrs", "tail", "motor", "spacer", "cover")


def win(shape, x0, x1, y0, y1, z0, z1):
    return shape & M._box(x0, x1, y0, y1, z0, z1)


# ----------------------------------------------------------------- overview
def overview():
    m = made()
    off = {"foam": (0, 0, 0), "film": (0, 0, 38), "traces": (0, 0, 76), "fsrs": (0, 0, 114), "tail": (0, 0, 152),
           "motor": (0, -95, -20), "spacer": (0, 0, 190), "cover": (0, 0, 228),
           "base": (-60, 0, 150), "cell": (-105, 0, 150), "module": (-145, 0, 150), "iface": (-185, 0, 150),
           "lid": (-230, 0, 150)}
    parts = []
    for k in m:
        p = m[k]
        p.explode = off[k]
        parts.append(p)
    return bv.overview(parts, OUT / "overview.png", "StepCue prototype: every component, pulled apart",
                       subtitle="Numbered in build order: the insole (1 to 8) is built first, then the heel pod (9 to 13). "
                                "Seen from the front left and above",
                       elev=24, azim=-125, size=(11, 7.5), dpi=150, key=True)


# ----------------------------------------------------------------- making sketches
def sheet(part_, neighbours, dwg_no, title, material, notes, views=("front", "top", "right"), view_shape=None,
          inset_view=(24, -58), rev="P1", history=()):
    """As build_views.component_sheet, but with a choice of views: a flat sheet part (an insole
    layer) is drawn in plan only, since its edge views are a fraction of a millimetre thick."""
    from drawing import Sheet, project_views
    work = DWG / f"_{dwg_no}_views"
    vs = project_views(view_shape if view_shape is not None else part_.shape, work)
    inset = bv.where_it_goes(part_, neighbours, work / "where.png", elev=inset_view[0], azim=inset_view[1])
    s = Sheet(project="StepCue", title=title, dwg_no=dwg_no, rev=rev, author="Amish Chadha",
              date=history[-1][2] if history else DATE,
              concept="BUILD PLAN SKETCH, PLAN NOT YET BUILT", scale=None, material=material,
              revisions=list(history) or [(rev, "Making sketch for the prototype build plan", DATE, "AC")])
    s.add_ortho(vs, list(views))
    s.add_image(str(inset), 276, 30, 140, 70, label="Where it goes", sublabel="This part in colour, its neighbours in grey")
    s.add_notes("How to make it and how it fits", notes, x=276, y=112, width=140)
    s.save(DWG / dwg_no)
    shutil.rmtree(work, ignore_errors=True)
    return DWG / f"{dwg_no}.png"
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

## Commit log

2026-09-24 Initial scaffold: standard open hardware layout, CERN-OHL-S v2 + MIT licenses
    Claude-Session: https://claude.ai/code/session_01XuhhSU4W6fYhgCfURbrkut
    [bom.csv]
2026-09-25 Adopt portfolio kit v1.3.0: session commands, scale figure, 3D viewer, flow diagrams
    Adds .claude/commands (/populate, /advance-trl3, /rein-in, /refresh-media)
    so every Claude Code session starts from the standard prompts, and extends
    concept media with a 1.75 m scale figure, an interactive glTF viewer and
    system or energy flow diagrams. TRL cap 3 unchanged.
    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
2026-09-25 Kit v1.3.1: renderer fixes from the TremorTrace pilot
    Context scale parts for small objects, cutaway exclusions, and text
    labels in flow diagrams.
    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
2026-09-25 Populate stepcue to a strong TRL 2 with concept media (overnight batches 4 and 5)
    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
    [bom.csv]
2026-09-25 Advance stepcue to TRL 3 (batch 4)
    Decisions approved by Amish 2026-09-25 recorded in DDR-001. TRL 4 is on hold.
    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
    [bom.csv, stepcue-assembly.step, stepcue-assembly.stl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]
2026-09-26 Accept all recommendations (DDR-002), switch footer to designmolecule.com, add README write-up with new inspiration point
    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
    [bom.csv, stepcue-assembly.step, stepcue-assembly.stl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]
2026-09-27 Product appearance model and photoreal renders
    Adds cad/src/product_model.py (appearance model for renders only, all main
    dimensions from model.py) and Blender renders in media/render-*.png,
    captioned with the project, repository and viewing direction. README leads
    with the product render; trl stays 3.
    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
2026-10-01 Image quality pass: legible exploded views, flow diagrams and drawing sheets
    Kit 1.6.1 image layout: the parts list sits in its own column, number bubbles sit on visible parts and never overlap, small parts get a leader, pictures are cropped to the subject, flow labels keep numbers with their units, and sheet captions and the revision table no longer overprint. Concept images, blueprint and general arrangement sheet regenerated; repo-specific labels moved clear of other text and lines.
2026-10-02 Kit 1.7.0: constructable design, illustrated build plan and design decisions register
    The design is now constructable: every part can be made and fits its neighbours, with each change recorded in a Design for construction decision record (made under Amish's 2026-09-30 instruction; ope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
    FlexHand also credits Dr. Geeti Chadha as a contribut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
    [bom.csv, stepcue-assembly.step, stepcue-assembly.stl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]
2026-10-02 Record Amish's approval of the open-decision recommendations
    Amish approved the recommendation on every open decision in the design decisions register ("i approve your recommendations for all 555 open decisions.", 2026-10-02). Each decision is moved to Decisio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
2026-10-03 Carry approved follow-ups into the design and redo photoreal renders
    Amish approved the follow-up actions from the open-decision sign-off ("APPROVED CHANGES, COMPLETE THESE", 2026-10-02), the design-for-construction change tables in ten repos, the last wave's open dec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
    [bom.csv, stepcue-assembly.step, stepcue-assembly.stl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]

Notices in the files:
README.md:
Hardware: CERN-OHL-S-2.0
